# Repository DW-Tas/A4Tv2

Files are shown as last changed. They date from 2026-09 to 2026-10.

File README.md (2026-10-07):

# A4Tv2: A new version of [A]nother [4]01x [T]oolhead

[][cc-by-nc-sa]

A4Tv2 is a new version of [A4T](https://github.com/DW-Tas/A4T), from: ko-fi (https://ko-fi.com/O5O5OCC0K) [DW-Tas](https://github.com/DW-Tas)

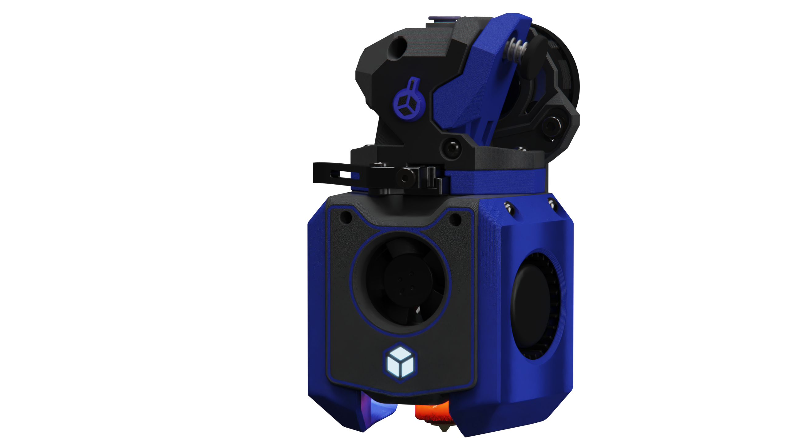
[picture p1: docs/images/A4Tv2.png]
A4Tv2 toolhead render


> [!TIP]
> **A4Tv2 is a prerelease.** This design is still in development and should be treated as experimental. It is not a fully documented release.

## Documentation and assembly

A basic illustrated [A4Tv2 toolhead assembly guide](docs/toolhead_build.md) is now available. It covers preparation of the printed parts, fan and duct installation, hotend and extruder assembly, wiring, and mounting the completed toolhead to the carriage.

A4Tv2 remains a prerelease, so the guide and hardware details may change as development continues. Check that the instructions and fastener lengths are suitable for your selected hotend, extruder, ducts, and carriage before assembly.

## Files

- `CAD/` contains STEP files, including the A4Tv2 assembly STEP and ZIP exports.
- `STL/` contains exported STL files.
- `3MF/` contains exported 3MF files.

## Fan Options

- **`4015:`** Finding *GOOD* 4015 fans is a challenge. Peopoly [Magneto X Lancer Extruder Side Turbo Fans](https://peopoly.net/products/magneto-x-lancer-extruder-side-turbo-fan?variant=50568975810842) have amazing flow and pressure (not far of 5015s), but, they require hardware PWM and slicer configuration to compensate for slow spin up time (around 1 second).

  ⚠️ *These fans are single-source, so availability can be inconsistent and shipping costs can be quite high.*

- **`4010:`** Two duct options are available:
  - **Backflow inhibitor built into duct:** Designed for GDStime 12k 4010 fans, with the backflow inhibitor built in. Take the front off the fan before installing into the duct.
  - **Generic duct:** Fits most 4010 fans. Requires backflow inhibitors to be installed in the same way as A4T. Good for reusing fans with inhibitors already glued in place.

> [!WARNING]
>## UHF hotend screw warning
>
>The UHF versions, including Rapido X, use countersunk screws to hold the hotend to the main body. The wedge shape of a countersunk screw may put outward force on the printed plastic and cause it to creep or split over time. Treat these versions as experimental and inspect the printed part for cracking or deformation. Feedback encouraged.

<br/><br/>
> [!TIP] 
> ### You can help support the development of this project.<br/>
> Donate at https://ko-fi.com/dwtas<br/>
ko-fi (https://ko-fi.com/dwtas)
<br/><br/>

This work is licensed under a
[Creative Commons Attribution-NonCommercial-ShareAlike 4.0 International License][cc-by-nc-sa].

[][cc-by-nc-sa]

[cc-by-nc-sa]: http://creativecommons.org/licenses/by-nc-sa/4.0/
[cc-by-nc-sa-image]: https://licensebuttons.net/l/by-nc-sa/4.0/88x31.png
[cc-by-nc-sa-shield]: https://img.shields.io/badge/License-CC%20BY--NC--SA%204.0-lightgrey.svg

### License clarification regarding non-commercial use:
The non-commercial aspect of this license is for cases where A4Tv2 is the product, not the use of A4Tv2 to create products.<br/>
For example, if you wish to sell A4Tv2 as a product, you would need to seek a commercial license before doing so. </br>
It is NOT intended to prevent the use of A4Tv2 in a printer that you use to provide commercial services. If you want to run A4Tv2 as a toolhead for your print farm printers, go right ahead.

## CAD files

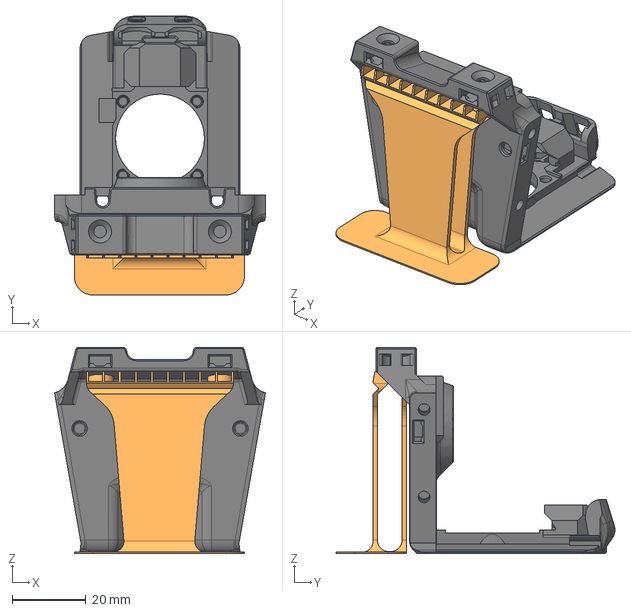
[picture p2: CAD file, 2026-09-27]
CAD/main_bodies/main-body_dragon-rapido_sherpa_xol.step
57.1 x 75.4 x 55.8 mm

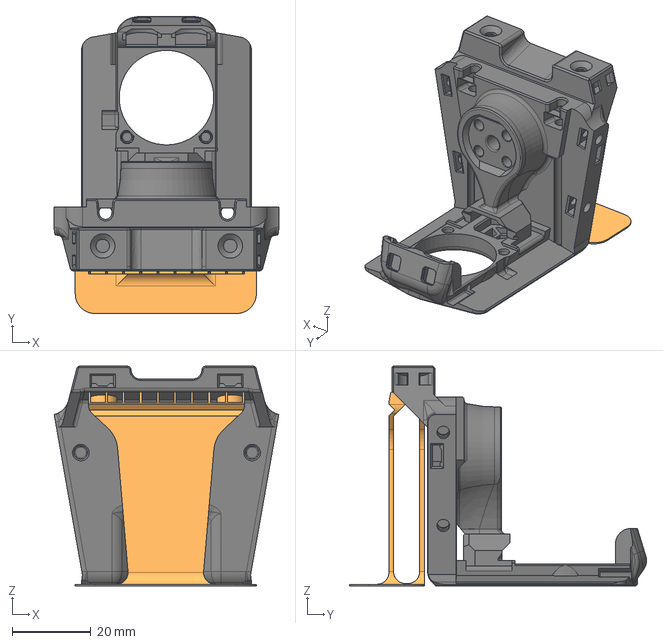
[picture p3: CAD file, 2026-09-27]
CAD/main_bodies/hex-main-body_revo-voron_sherpa_xol.step
57.1 x 75.4 x 55.8 mm

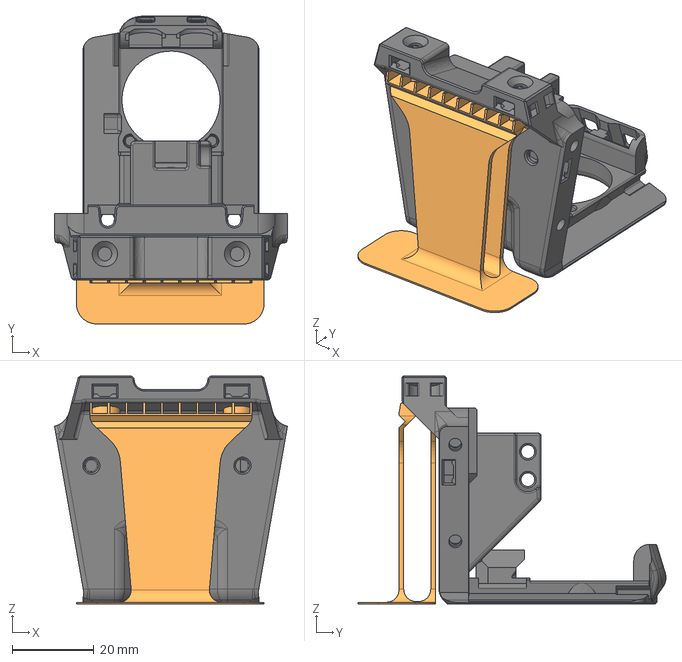
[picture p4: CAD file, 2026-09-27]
CAD/main_bodies/main-body_bambulab_o2_xol.step
57.1 x 75.4 x 55.8 mm

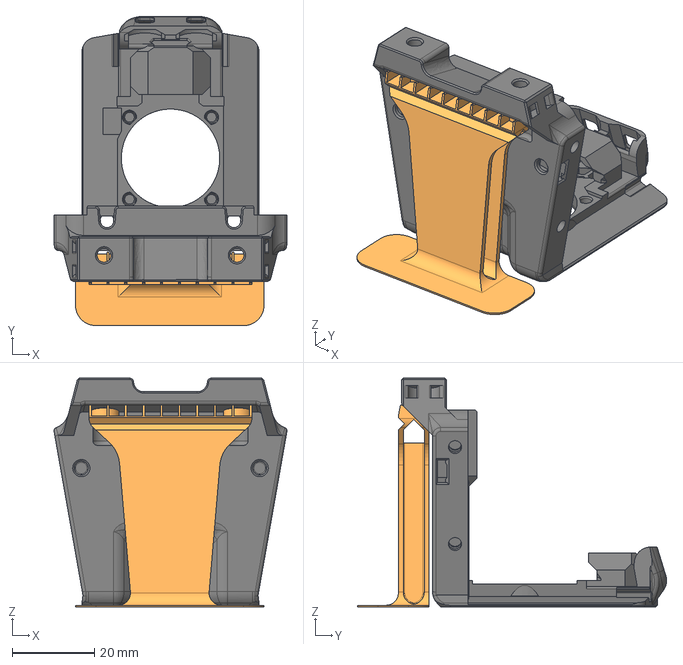
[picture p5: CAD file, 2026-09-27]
CAD/main_bodies/main-body_dragon-rapido-UHF_sherpa_tap.step
56.8 x 75.4 x 55.8 mm

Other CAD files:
CAD/main_bodies/hex-main-body_chube-compact_sherpa_xol.step
CAD/main_bodies/hex-main-body_bambulab_sherpa_xol.step
CAD/main_bodies/hex-main-body_chube-compact_o2_xol.step
CAD/main_bodies/main-body_dragon-standard_o2_xol.step
CAD/main_bodies/main-body_bambulab_o2_tap.step
CAD/main_bodies/main-body_dragon-rapido-UHF_o2_tap.step
CAD/main_bodies/hex-main-body_dragon-standard_o2_tap.step
CAD/main_bodies/hex-main-body_revo-voron_o2_tap.step
CAD/main_bodies/main-body_chube-compact_o2_xol.step
CAD/main_bodies/hex-main-body_dragon-standard_o2_xol.step
CAD/main_bodies/hex-main-body_dragon-standard_sherpa_xol.step
CAD/main_bodies/main-body_rapido-X_sherpa_xol.step
CAD/main_bodies/hex-main-body_revo-voron_o2_xol.step
CAD/main_bodies/hex-main-body_dragon-rapido_sherpa_xol.step
3MF/ducts/A4Tv2_4010_Ducts.3mf
3MF/ducts/A4Tv2_4010_Ducts[inbuilt_inhibitors].3mf
3MF/ducts/A4Tv2_4015_Ducts.3mf
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

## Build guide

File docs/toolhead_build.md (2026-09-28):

# A4Tv2 Toolhead Assembly

This guide covers the basic assembly order for the A4Tv2 toolhead. The renders show a representative build; your hotend, extruder, carriage, ducts, and fastener lengths may differ depending on the parts selected.

Read through the complete guide before starting. Prepare the correct printed parts and hardware for your configuration, check that all parts fit without excessive force, and keep wires clear of fans, hot components, and screw paths throughout the build.

> [!NOTE]
> This is an initial assembly guide based on the current CAD. Verify fastener lengths against your selected components and do not use a screw that can bottom out or contact electronics.

## Assembly Steps

<!-- markdownlint-disable MD033 -->

| Step | Instructions | Reference |
| ---: | --- | --- |
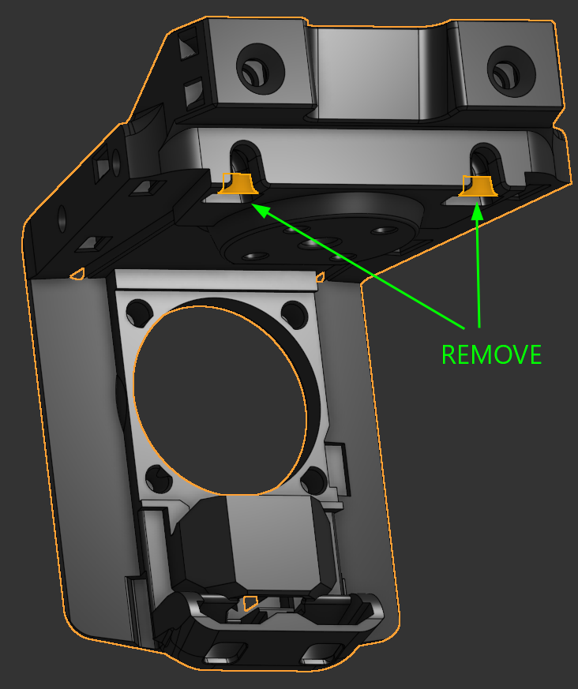
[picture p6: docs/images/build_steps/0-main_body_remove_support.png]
Built-in supports to remove from the main body
| **0** | **Remove the built-in supports.** Remove the two highlighted supports from the underside of the main body. Clean away any remaining support material without damaging the surrounding slots. |  |
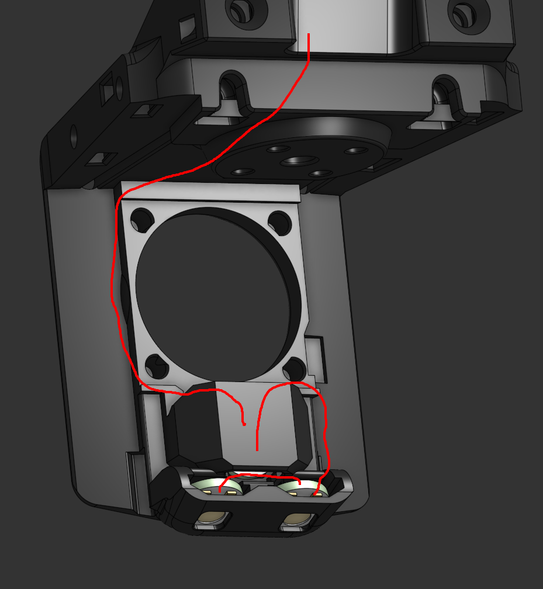
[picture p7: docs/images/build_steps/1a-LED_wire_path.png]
LED wire routing below the hotend fan
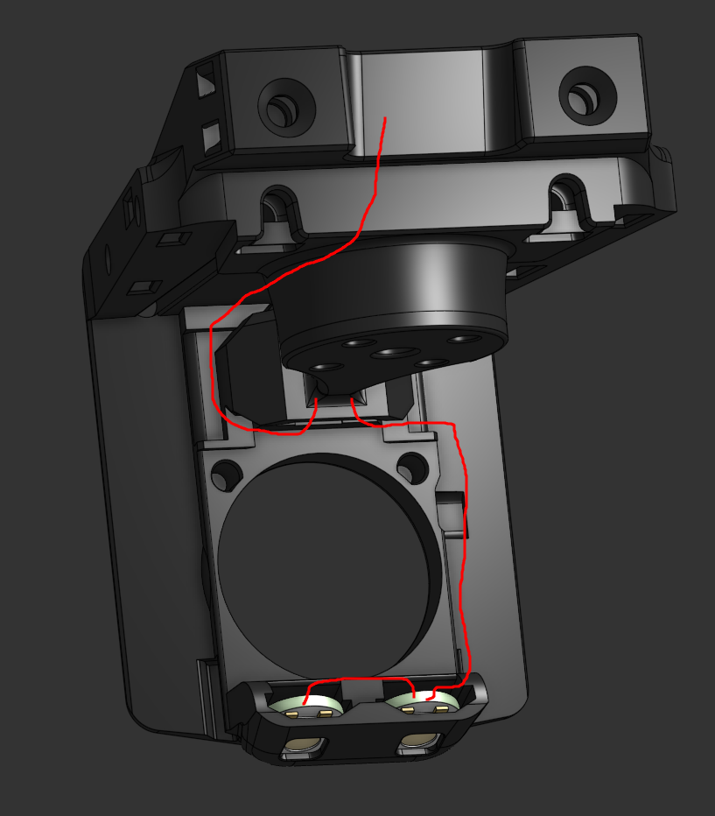
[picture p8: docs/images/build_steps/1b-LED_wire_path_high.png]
Alternative high LED wire routing
| **1** | **Install and route the LED wiring.** Fit the LED carrier and route the wires through the main body as shown. Either illustrated route may be used depending on the available clearance. Keep the wires tucked against the body, away from the 2510 fan opening, hotend, and all screw holes. |   |
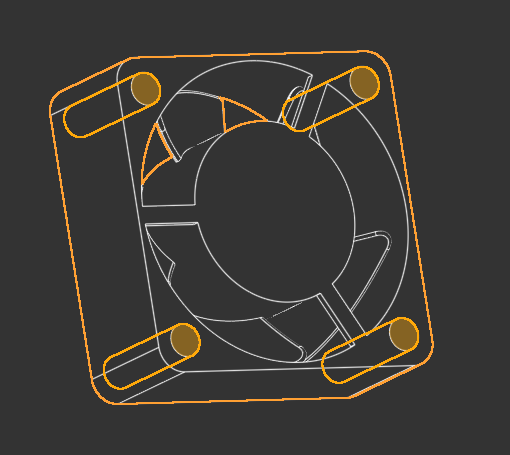
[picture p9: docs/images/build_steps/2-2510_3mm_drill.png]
2510 fan mounting holes to open to 3 mm
| **2** | **Open the 2510 fan mounting holes.** Carefully run a 3 mm drill through the four mounting holes of the 2510 hotend fan. Drilling by hand is recommended so the fan frame is not damaged. Clear away all swarf before installation. |  |
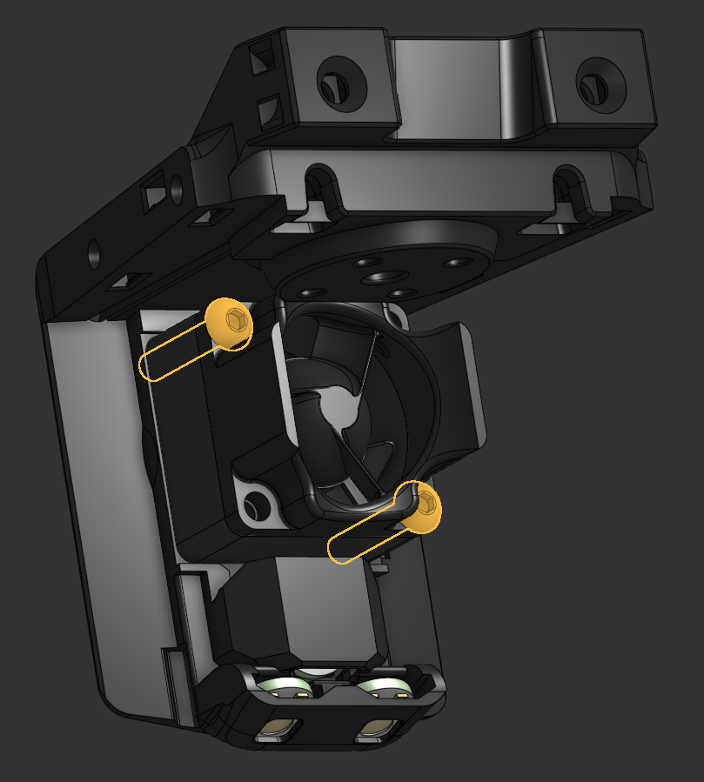
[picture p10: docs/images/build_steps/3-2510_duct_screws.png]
2510 hotend fan retaining screws
| **3** | **Install the 2510 hotend fan.** Place the fan in the main body in the orientation shown, with its cable following the route established in step 1. Install the two retaining screws and tighten them evenly.<br><br><blockquote>⚠️ <strong>Warning: Do not overtighten</strong><br>These screws form their own threads in the printed plastic. Keep each screw straight, turn it slowly, and tighten it only until the fan is held securely. Excessive force can strip the plastic threads or distort the fan frame.</blockquote> |  |
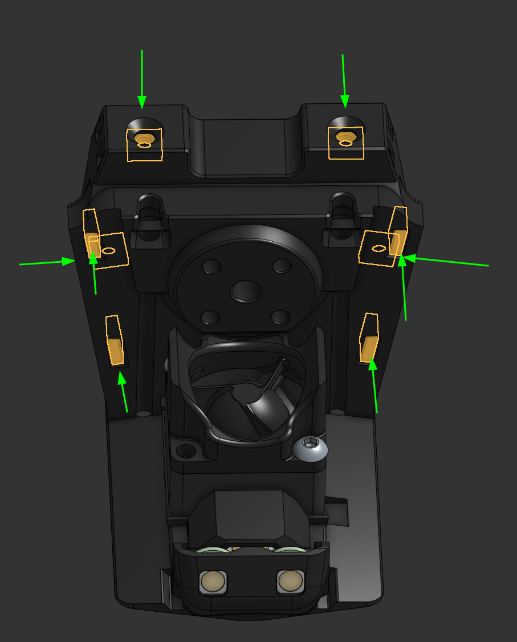
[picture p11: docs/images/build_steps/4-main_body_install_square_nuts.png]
M3 square nut locations in the main body
| **4** | **Install the square nuts.** Insert M3 square nuts into each highlighted pocket in the main body. Make sure every nut sits flat and that its threaded hole lines up with the corresponding screw path. |  |
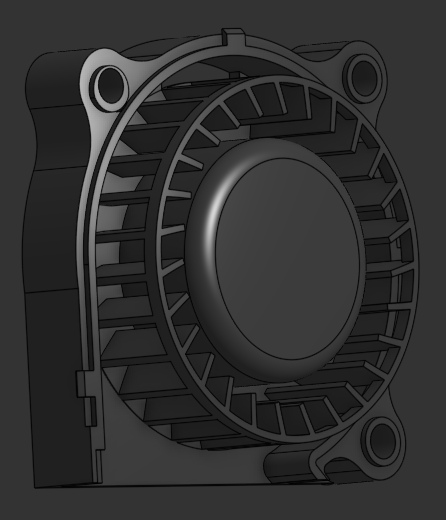
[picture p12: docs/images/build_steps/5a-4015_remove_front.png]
Front cover removed from a 4015 blower
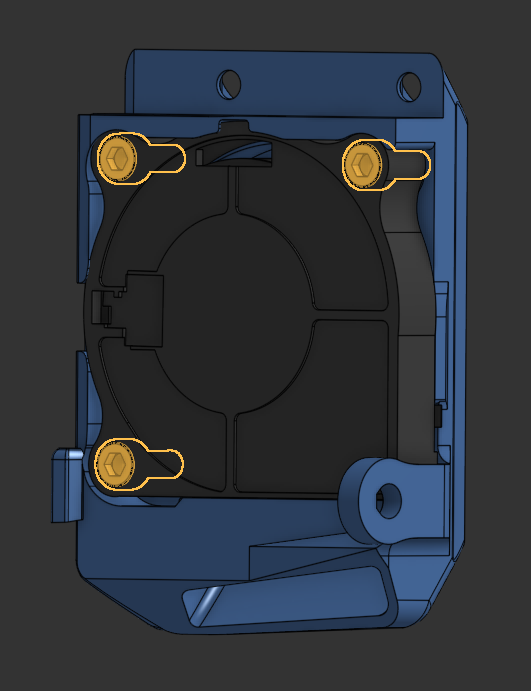
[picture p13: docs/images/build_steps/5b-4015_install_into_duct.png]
4015 blower installed in a printed duct
| **5** | **Fit the 4015 blowers into the ducts.** Remove the front cover from each 4015 blower, then place the blower into its printed duct in the orientation shown. Refit the cover if required by your fan and duct combination. The fan should be a light friction fit; do not force it into the duct. Secure the fan with the three highlighted screws, then repeat for the opposite side.<br><br><blockquote>⚠️ <strong>Warning: Check the screw length and do not overtighten</strong><br>M3x8 SHCS are normally used, but some fans require M3x6 SHCS. Confirm that the screws are the correct length for your fan before tightening them. These screws form their own threads in the printed plastic, so keep each screw straight, turn it slowly, and tighten it only until the fan is held securely. Excessive force can strip the plastic threads or damage the fan.</blockquote> |   |
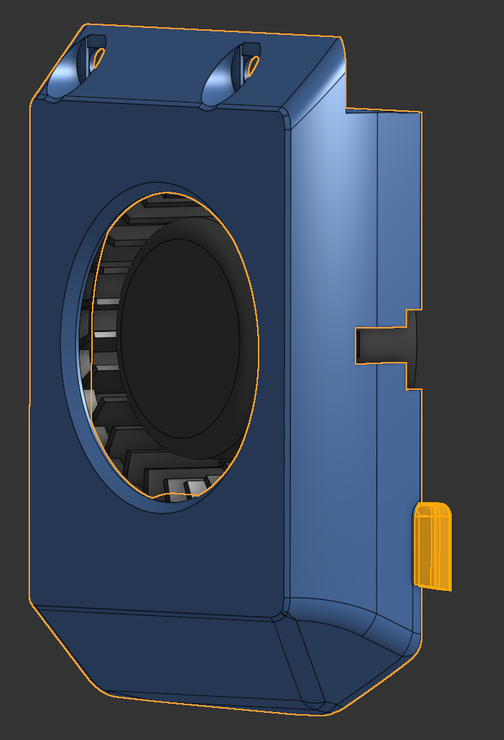
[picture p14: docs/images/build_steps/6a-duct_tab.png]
Locating tab on the part-cooling duct
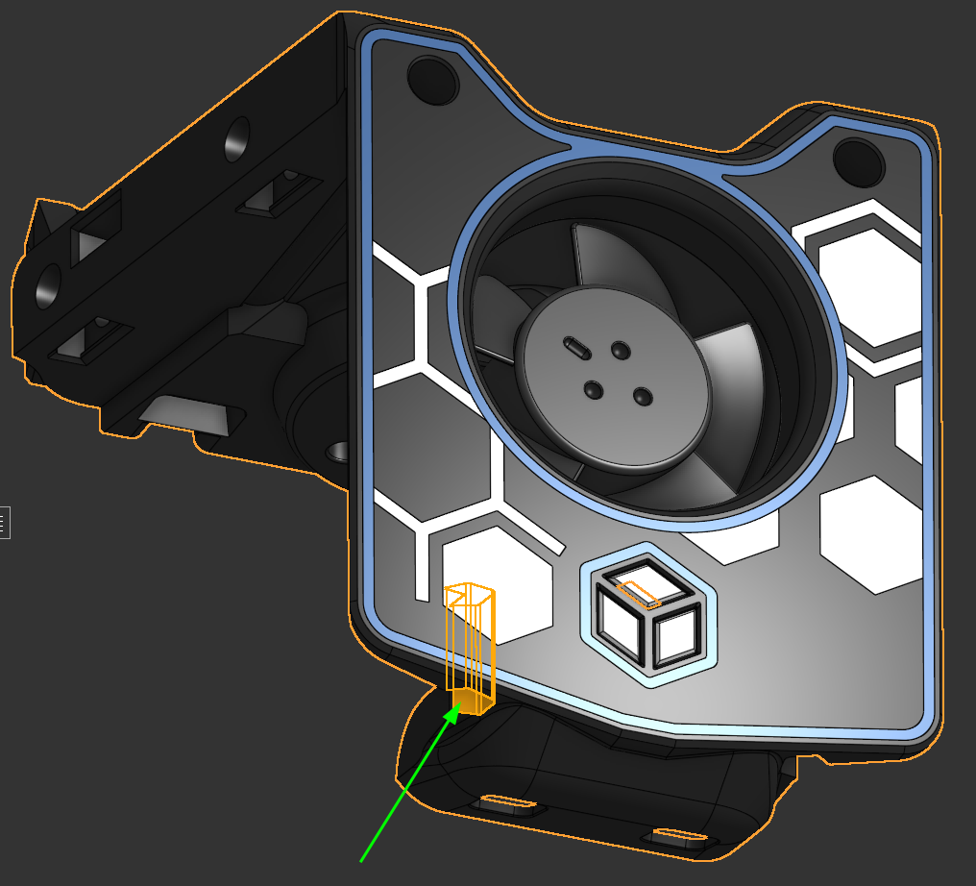
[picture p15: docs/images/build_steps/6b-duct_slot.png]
Matching duct slot in the main body
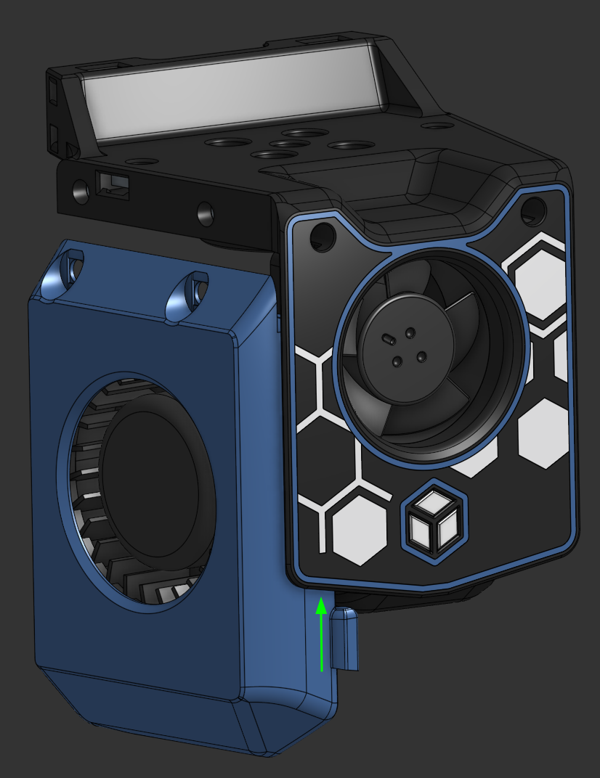
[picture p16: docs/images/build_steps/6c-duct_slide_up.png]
Sliding the first duct upward into place
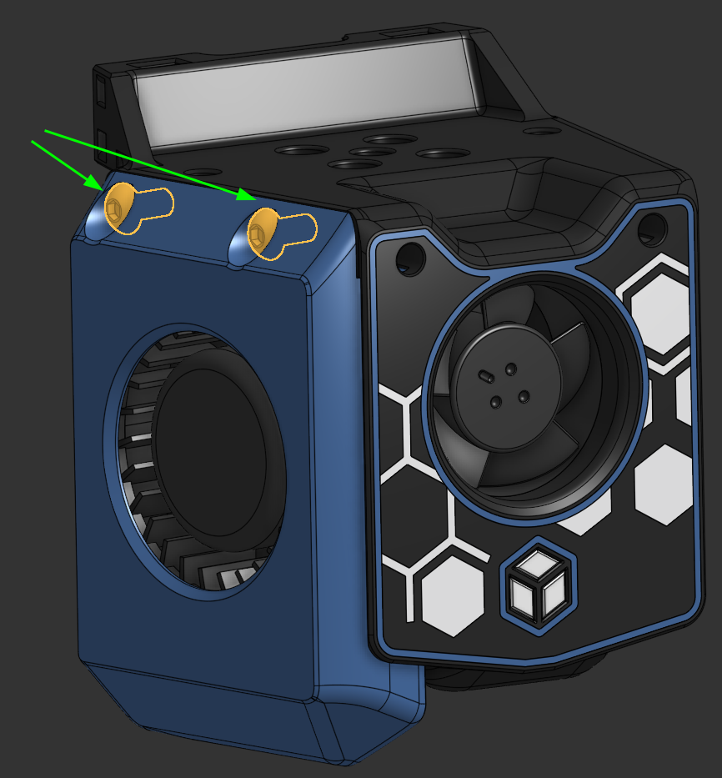
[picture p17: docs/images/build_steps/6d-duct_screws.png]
Retaining screws for the first duct
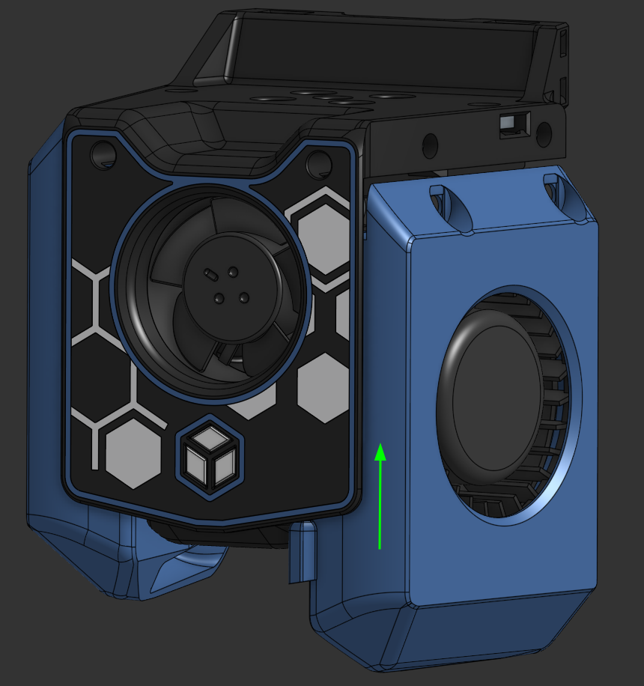
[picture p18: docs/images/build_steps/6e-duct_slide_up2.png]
Sliding the second duct upward into place
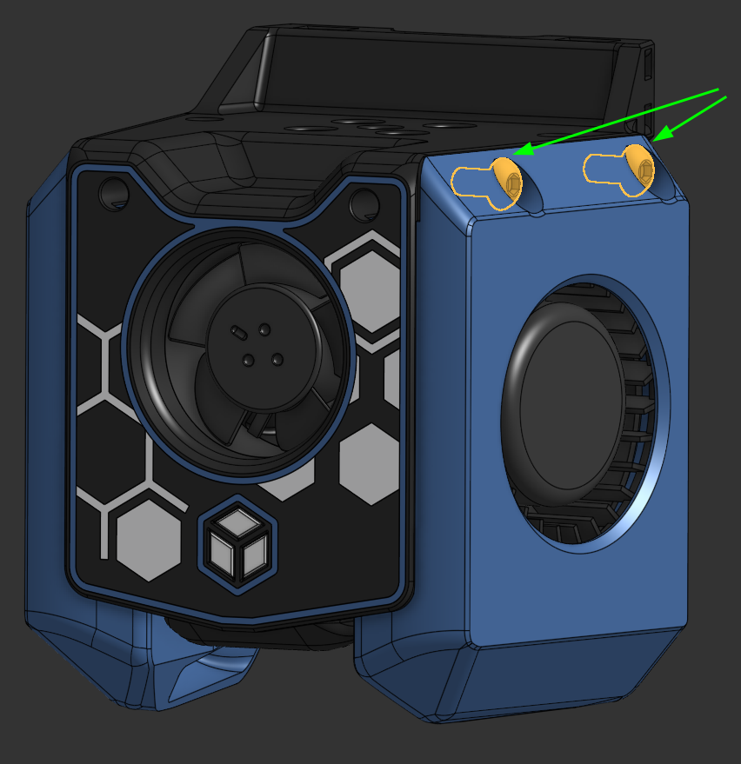
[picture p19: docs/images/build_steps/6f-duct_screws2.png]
Retaining screws for the second duct
| **6** | **Attach both part-cooling ducts.** Locate the small tab on the duct and engage it with the matching slot in the main body. Slide the first duct upward until it is fully seated, then install its two upper retaining screws. Repeat the same tab, slide, and screw sequence for the duct on the other side. Check that both ducts sit flush and that no wiring is trapped between parts. |       |
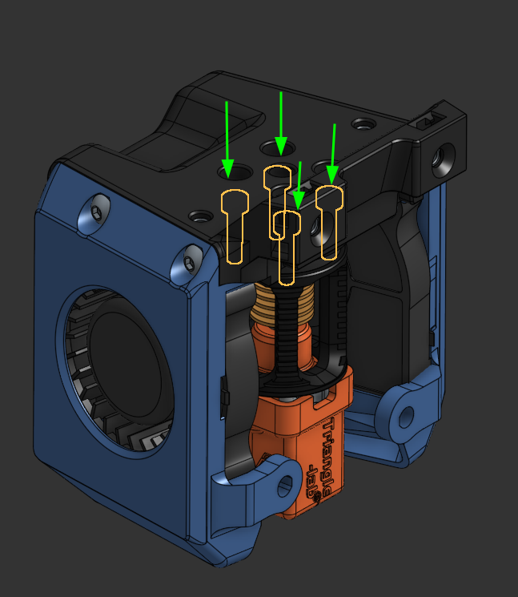
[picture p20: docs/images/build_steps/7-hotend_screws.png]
Four hotend mounting screws
| **7** | **Install the hotend.** Insert the hotend into the main body from below and align its mounting holes. Install the four hotend screws from above in the positions shown. Tighten them gradually in an alternating pattern so the hotend seats evenly. |  |
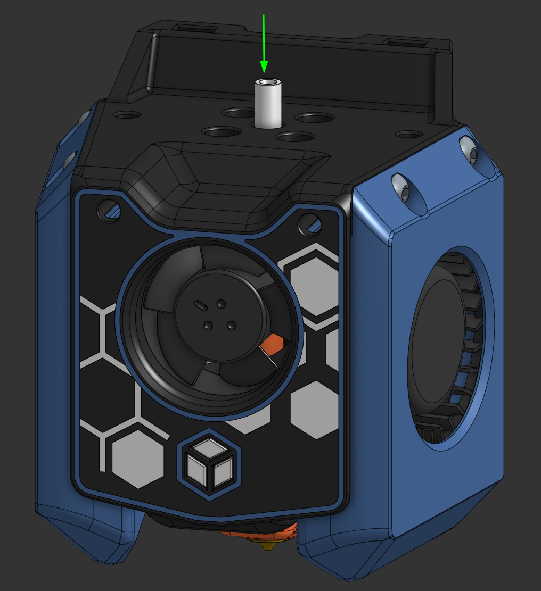
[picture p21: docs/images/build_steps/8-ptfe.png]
PTFE tube installed above the hotend
| **8** | **Install the PTFE tube.** Cut the PTFE tube squarely to the length required between the hotend and extruder, then insert it fully into the hotend filament path. The tube must not buckle or leave a gap when the extruder is fitted. |  |
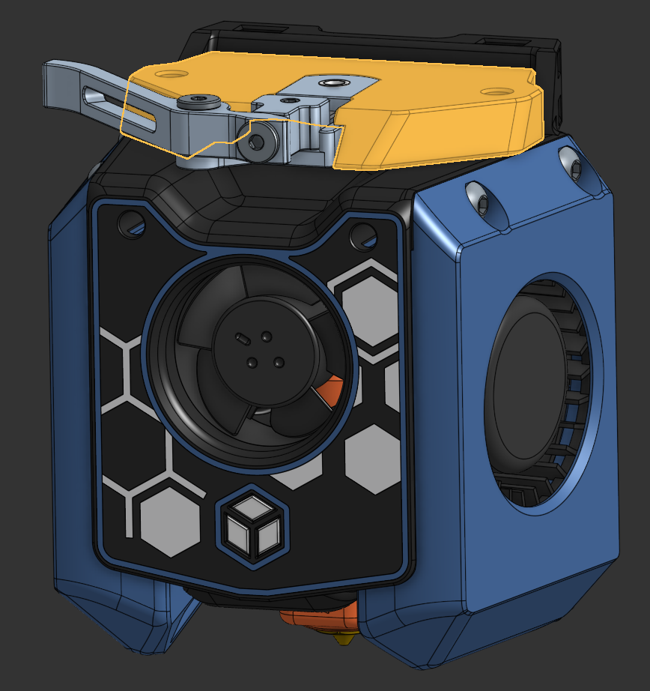
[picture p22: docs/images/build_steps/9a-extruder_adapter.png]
Extruder adapter positioned on the main body
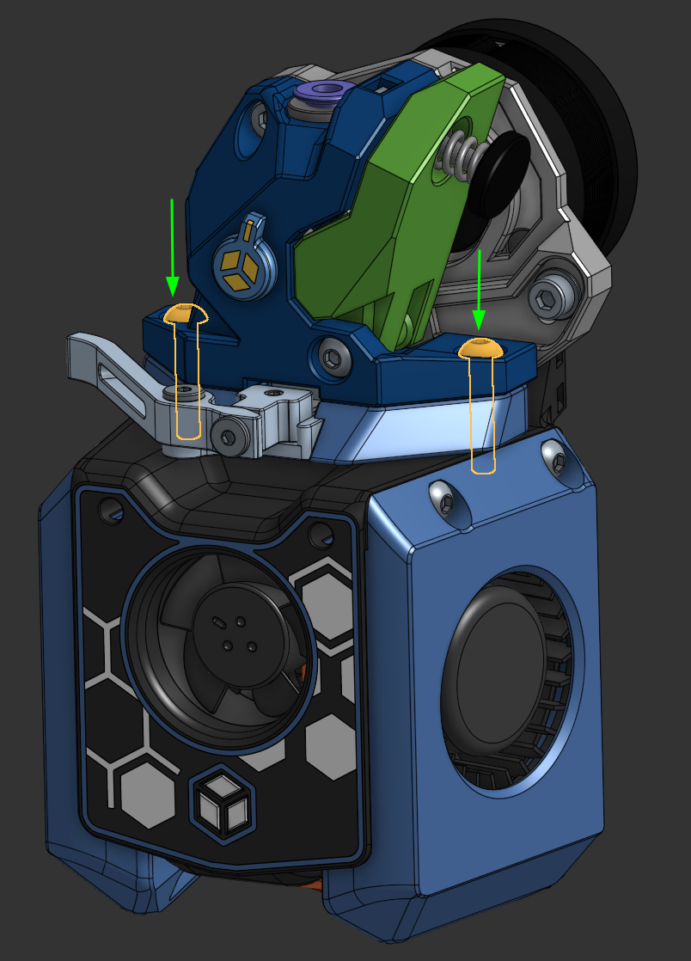
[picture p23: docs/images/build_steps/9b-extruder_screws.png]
Extruder mounting screw locations
| **9** | **Install the extruder and adapter.** Place the correct extruder adapter for your configuration over the PTFE tube and align it with the main body. Set the extruder onto the adapter, confirm that the filament paths line up, and install the two mounting screws shown. Tighten evenly without crushing the printed parts. |   |
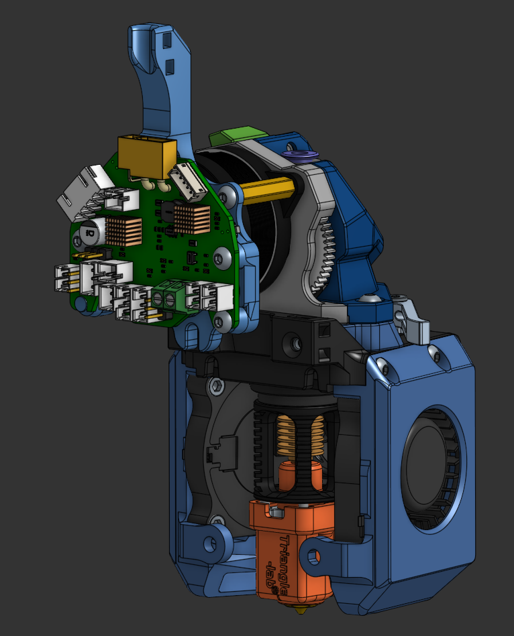
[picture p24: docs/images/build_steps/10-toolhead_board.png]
Toolhead board installed behind the extruder
| **10** | **Install the toolhead board.** Attach the toolhead board and its mount to the rear of the extruder assembly. Confirm that the board is supported at all mounting points and that screw heads or standoffs cannot contact solder joints. Connect and secure the wiring, leaving enough slack for service but keeping it clear of the belts and carriage mounting points. |  |
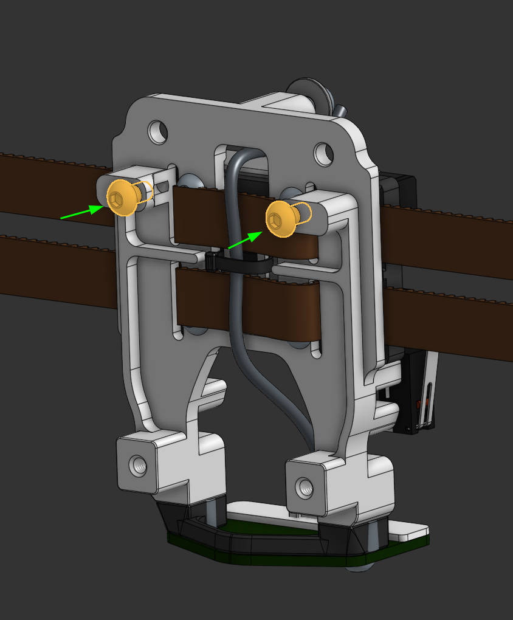
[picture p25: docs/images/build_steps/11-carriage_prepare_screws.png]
Upper carriage screws prepared for mounting the toolhead
| **11** | **Prepare the carriage screws.** Install the two upper mounting screws in the carriage as shown, leaving their heads proud so the toolhead mounting slots can hook over them. Route the carriage cable between the belts and away from the screw heads. |  |
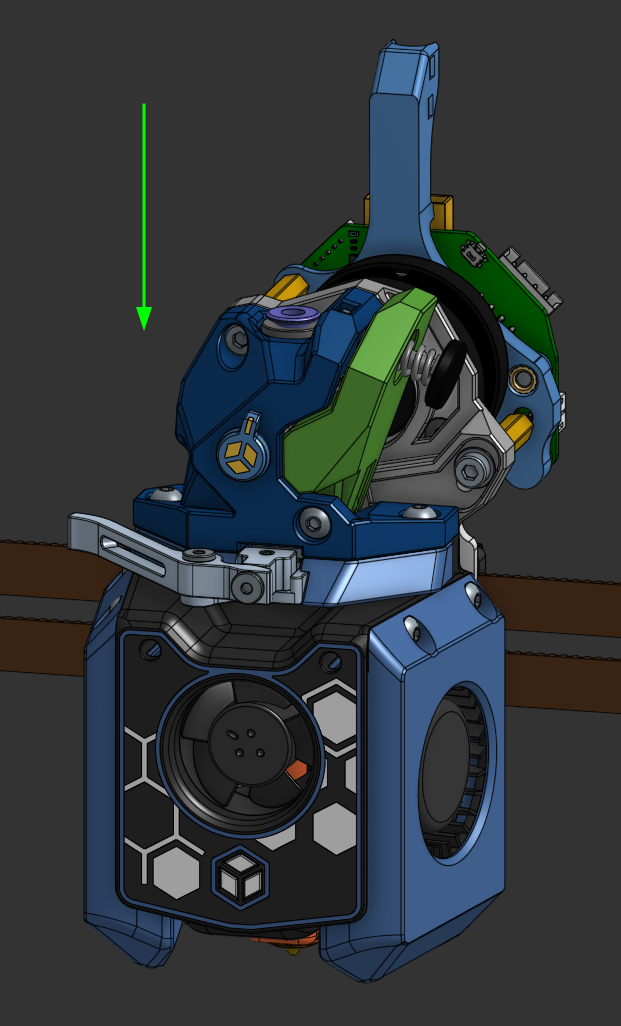
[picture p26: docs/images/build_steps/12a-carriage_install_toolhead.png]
Installing the toolhead onto the prepared carriage screws
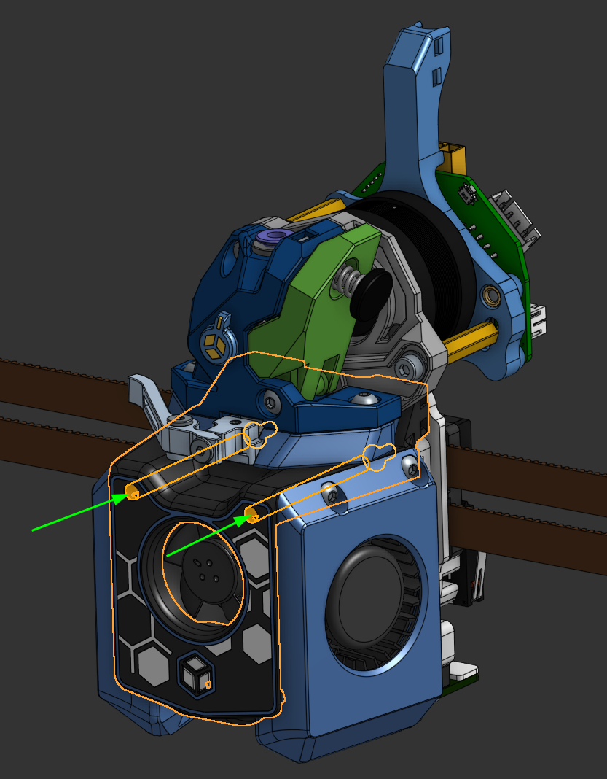
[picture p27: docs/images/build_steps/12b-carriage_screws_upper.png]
Upper toolhead-to-carriage screw locations
| **12** | **Mount and secure the top of the toolhead.** Align the mounting slots in the completed toolhead with the two prepared carriage screws, then slide the toolhead into place until it is fully seated.<br><br><blockquote>💡 <strong>Tip: Use a 2 mm hex driver</strong><br>Pass the driver through the long access holes in the toolhead to reach and tighten the two carriage screw heads.</blockquote><br>Support the toolhead while tightening both upper carriage screws. |   |
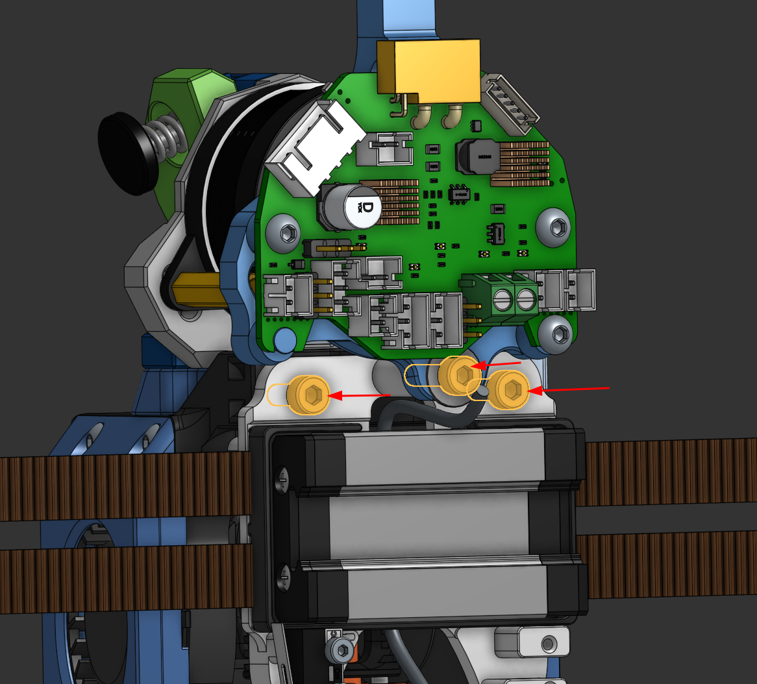
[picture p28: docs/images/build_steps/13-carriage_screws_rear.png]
Rear toolhead board mount screw
| **13** | **Secure the rear mounting point.** Install and tighten the highlighted rear fastener through the toolhead board mount into the carriage. Check from the side that the mount is seated flat and that no cable is trapped behind it. |  |
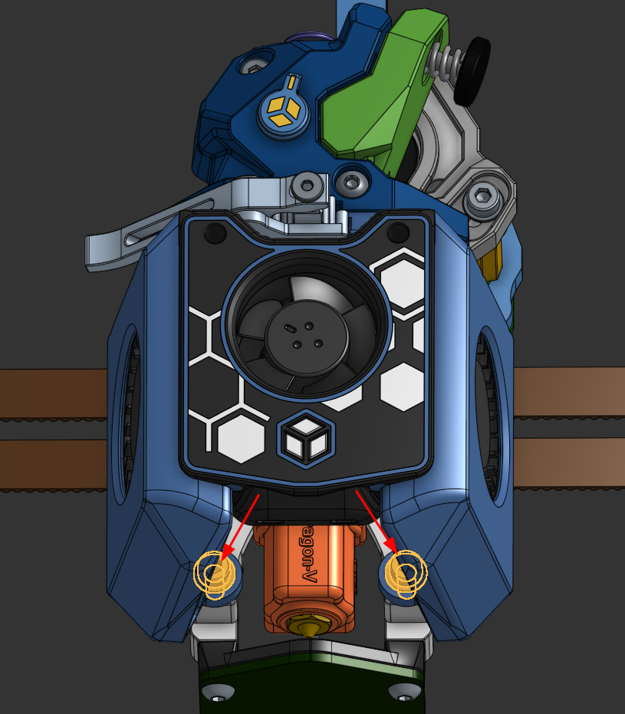
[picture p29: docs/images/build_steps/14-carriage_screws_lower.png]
Two lower toolhead-to-carriage screws
| **14** | **Install the lower carriage screws.** Insert and tighten the two lower mounting screws in the positions shown.<br><br><blockquote>⚠️ <strong>Warning: Ball-end hex driver required</strong><br>The driver will enter each screw head at an angle, but the screw itself must enter the threads straight. Start each screw gently and confirm that it turns freely before tightening. If it binds or needs excessive force, stop, back it out, and realign it. Tightening a misaligned screw can strip the screw head or damage the threads.</blockquote><br>Check all carriage fasteners once more, then move the toolhead by hand through its full travel to confirm that the belts, wiring, ducts, and printed parts do not interfere. |  |

<!-- markdownlint-enable MD033 -->

## Final Checks

- Confirm that every fan spins freely and that its airflow direction is correct.
- Check that the hotend, extruder, ducts, toolhead board, and carriage fasteners are secure.
- Verify that no wire can touch the hotend, fan blades, belts, or moving carriage parts.
- Confirm that the PTFE path is straight and unobstructed by feeding filament through it by hand.
- Perform the printer's electrical, heater, fan, endstop, probe, and motion checks before heating the hotend or starting a print.

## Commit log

2026-09-28 add basic assembly guide
2026-09-28 threading to plastic warning
2026-09-28 screw to plastic warning
2026-09-28 rename default HEF ducts (used to say rapido)
    [Duct-HEF-default-UHF.3mf, Duct-HEF-default-UHF.step, Duct-HEF-default-UHF.stl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]
2026-10-01 wording update for inbuilt inhibitor ducts
2026-10-07 better define fan options
2026-10-08 replace 4015 duct files
    [A4Tv2_4015_Ducts.3mf, A4Tv2_4015_Ducts.step, A4Tv2_4015_Ducts.stl]
2026-10-15 update 4010 duct parts - split out inhibitors and tab savers
2026-10-24 Update all UHF main bodies - replace countersunk screws with shorter M2.4 screws
2026-10-24 update README note on UHF screws
2026-10-24 Update CAD assembly ZIP and remove uncompressed STEP
2026-10-30 add draft BOM

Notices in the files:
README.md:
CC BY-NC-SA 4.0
